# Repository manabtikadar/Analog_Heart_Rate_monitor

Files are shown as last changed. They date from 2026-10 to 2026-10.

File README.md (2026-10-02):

# ECG-Based Heart Rate Monitoring System

An analog ECG signal acquisition and conditioning system designed to capture, amplify, and filter the electrical signals generated by the human heart.

The project combines analog circuit design, PCB development, embedded hardware integration, and mechanical enclosure design to build a compact heart rate monitoring device.

---

## Project Overview

An electrocardiogram (ECG) records the electrical activity of the heart using electrodes placed on the body's surface. These signals have very low amplitudes and are susceptible to interference from power lines, electromagnetic sources, electrode contact variations, and body movements.

The objective of this project is to develop an analog signal conditioning circuit capable of amplifying weak ECG signals while reducing unwanted noise.

## System Architecture

The signal processing pipeline consists of multiple analog stages:

- **Signal Acquisition:** Collects electrical potential differences through body electrodes.
- **Signal Amplification:** Increases the amplitude of weak ECG signals using operational amplifier circuits.
- **Analog Filtering:** Attenuates unwanted frequency components and interference.
- **Embedded Hardware Integration:** Incorporates an ESP32 development module and display connections.
- **Signal Visualization:** Provides a display interface for presenting monitored signals and measurement information.

## Hardware Design

### Analog Circuit Design

The analog front-end is designed to handle low-amplitude ECG signals while accounting for noise and interference.

The circuit uses:

- Operational amplifiers for signal amplification.
- Resistor-capacitor networks for frequency-selective filtering.
- Feedback networks to control gain.
- Multiple signal conditioning stages to improve signal quality.

### PCB Development

The hardware was designed using **Altium Designer**, with a four-layer PCB architecture.

**PCB design highlights:**

- Two signal routing layers.
- Dedicated ground and power planes.
- Integrated ESP32 development module.
- On-board display connections and power routing.
- IC sockets and modular connectors for convenient maintenance.

The PCB was fabricated, and the components were assembled and soldered manually.

## Circuit Simulation and Validation

The analog circuit was modeled and evaluated using:

- **LTspice:** Analog circuit behavior and signal response analysis.
- **NI Multisim:** Circuit simulation and verification.

## Mechanical Enclosure

A custom enclosure was designed using **SolidWorks**.

**Design features:**

- Removable top cover for assembly and maintenance.
- Dedicated mounting space for the display and adjustment knobs.
- Ventilation openings for heat dissipation.
- Access points for the power supply and electrode connections.
- Compact design suitable for housing the integrated electronics.

## Tools and Technologies

| Category | Tools / Components |
|---|---|
| Circuit Design | Operational Amplifiers, Resistors, Capacitors |
| PCB Design | Altium Designer |
| Circuit Simulation | LTspice, NI Multisim |
| Embedded Hardware | ESP32 Dev Module |
| Mechanical Design | SolidWorks |
| Fabrication | PCB Fabrication, Manual Soldering, 3D Printing |

## Project Images

### PCB Implementation

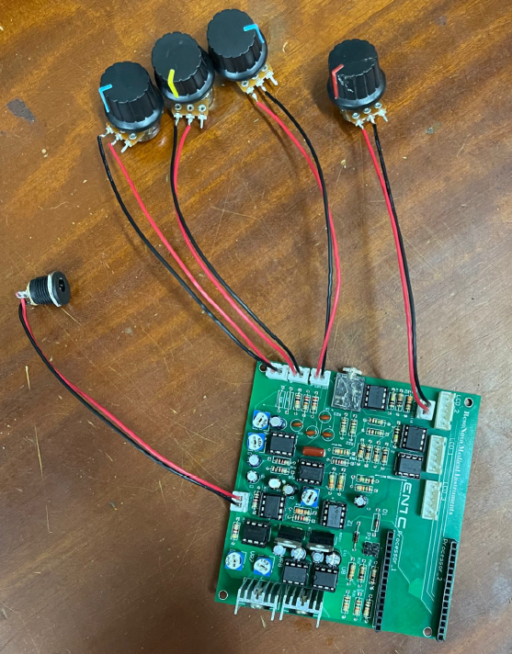
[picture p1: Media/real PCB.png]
Fabricated ECG PCB


### Enclosure Design

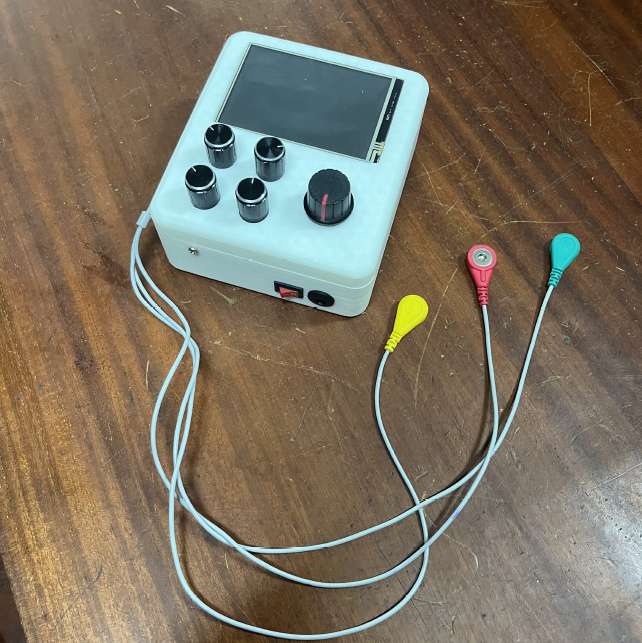
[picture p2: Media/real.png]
3D Printed Enclosure


## Key Learning Outcomes

- Analog signal amplification and filtering.
- ECG signal characteristics and noise sources.
- Multilayer PCB design and hardware integration.
- Circuit simulation and pre-fabrication validation.
- Mechanical enclosure design and prototyping.

## Contributors

- [Manab Tikadar](https://github.com/manabtikadar)

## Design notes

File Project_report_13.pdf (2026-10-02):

## Department of Electronic and Telecommunications Engineering

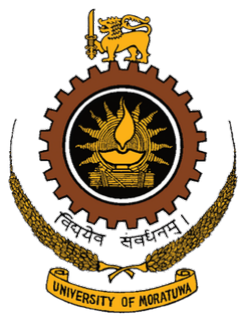
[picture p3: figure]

EN2091 Laboratory Practice and Project

Final Report

# ECG Heart Monitor

Charles J.

### Madugalle M.R.K.J.M.M.S.B

Kavishan G. T.
Wijesinghe C. D.

210079K
210351M
210285M
210720U

# Contents

ECG Heart Monitor - Resonova

## Abstract

Our project is regarding the development of a analog ECG heart monitor for real-time cardiac activity monitoring. Here we utilize only analog components to amplify heart-generated electrical
signals | and | for | signal | conditioning
to reduce noise. | It is then followed
by | analog-to-digital | conversion | and
subsequent | signal | processing | stages,
implemented | on | a | microcontroller.
Additionally, our project explores the integration of wireless communication for remote monitoring.

## 1 Introduction

An electrocardiogram (ECG) is a simple
diagnosis | technique | employed | to | assess
the heart’s electrical activity by detecting
electrical | signals | generated | during | each
heartbeat through electrodes fixed to the skin. The voltage difference between the right arm and left arm is magnified, incorporating a feedback mechanism through the right leg. ECG leads measure these voltages from the right arm, left arm, and right leg. The voltage signal’s amplitude ranges from 0.001 mV to 100 mV (typical value is 1 mV), with a frequency spanning from 0.01 Hz to 250 Hz. Amplifying this signal proves challenging due to the small amplitude of the raw ECG signals and subjection to corruption from various sources such as noise, power line interference, RF inteference, noise from electrode contact, stray capacitance, and bio signal artifacts induced by movements of the subject.

In our project we propse and implement a analog circuit to amplify the above eletrical signal and to perform filtering to reduce noise. We make use of only basic analog electrical devices such as resistors, capacitors and OpAmps in our design.

The below block diagram illustrates the stages of signal conditioning employed in our design.

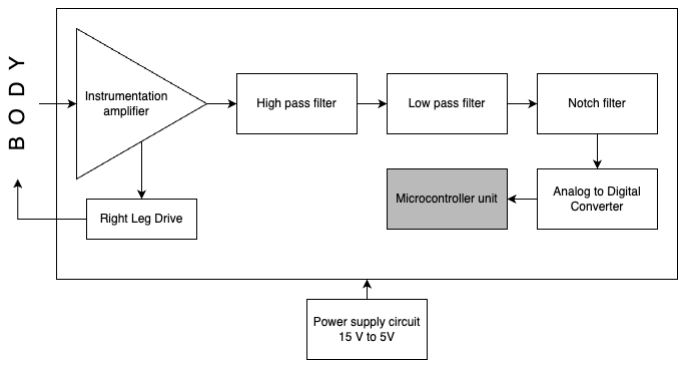
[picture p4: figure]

Figure 1: Block diagram of the circuit design

We implement the design of our circuit on a single PCB using the Altium PCB design software. All circuits were simulated
using | LTSpice | and | MultiSim | prior | to
implementation.

## 2 Functionality

### 2.1 Instrumentation amplifier

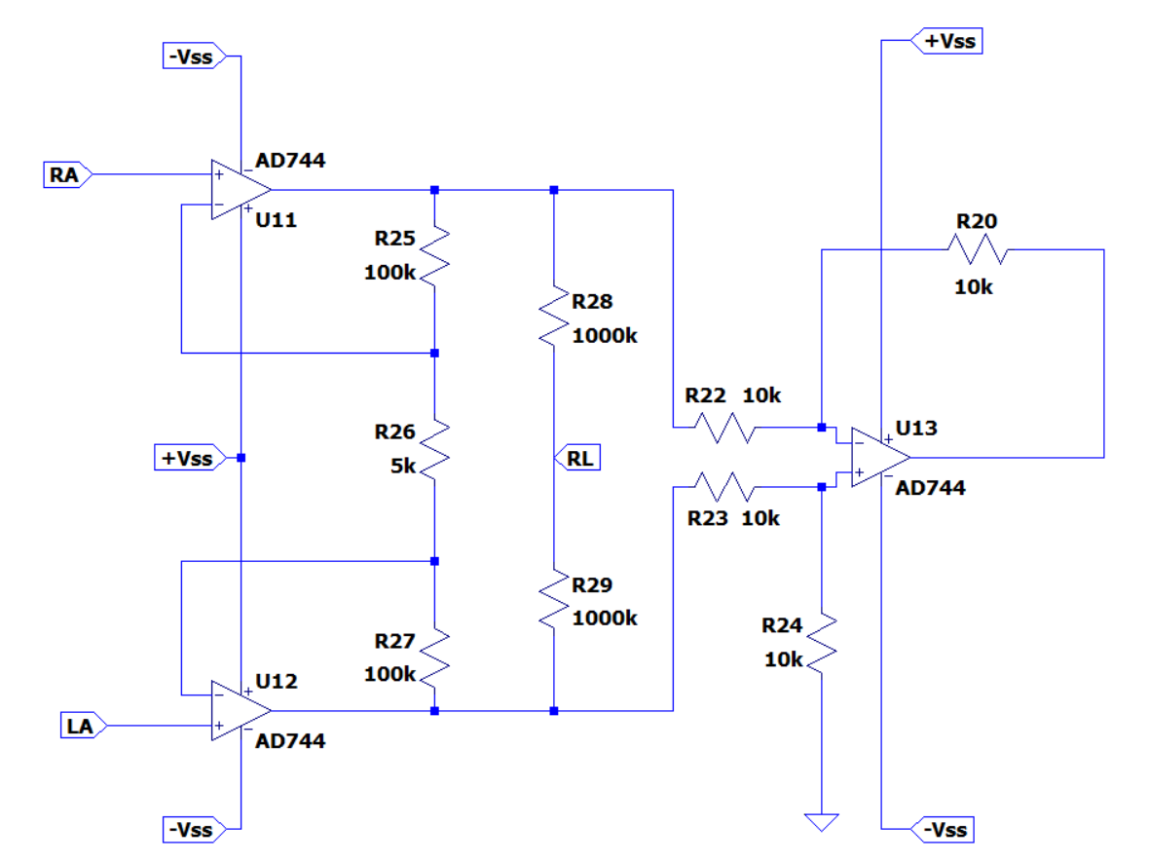
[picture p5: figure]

Figure 2: Instrumentation amplifier

The | primary | objective | of | the
Instrumentation | amplifier | is | amplifying
the small electrical signals generated by the
heart. | These ECG signals are typically in
the milli-volt range. | The instrumentation
amplifier amplifies this by amplifying the differential voltage between two electrodes while also rejecting common-mode inputs like interference from nearby power lines or

biosignal artifacts.

The proposed design of the instrumentation amplifier in our circuit operates using three TL071CP OpAmp ICs. We selected this IC because of its high Common Mode Rejection Ratio (CMRR). It has a minimum CMRR of 95 dB which was suitable enough for the amplification process. The input to the circuit is fed through two ECG leads. The gain can be adjusted using the variable resistor in the middle. We found through fine-tuning that preferred gain is 35.6.

### 2.2 Right Leg Drive

The Right Leg Drive (RLD) circuit is used to minimize the common-mode signal between the two input electrodes. This is done by taking the original signal, inverting and amplifying it and sending back to the body through the right leg. In the RLD configuration we use two TL072CP OpAmps; one acting as a unity gain buffer and the other as an inverting amplifier. We also include a high impedance resistor (0.5MΩ) before injecting the signal to the body for patient protection purposes. The gain of the RLD stage is 67.

### 2.3 Filter specifications

The selection of proper cutoff frequencies for filtering was a pivotal decision. The American Heart Association (AHA) suggests a minimum bandwidth of 150Hz for individuals aged 12 to 16 years and a minimum bandwidth of 125Hz for adults[1]. Based on this recommendation and analyzing several other designs, we chose the range of 0.01 Hz - 170 Hz to preserve accuracy while maintaining minimal noise.

We decided on implementing filter circuits using active filters to prevent loading effect. Furthermore, we used TL072CP OpAmp ICs when implementing the filter circuits.

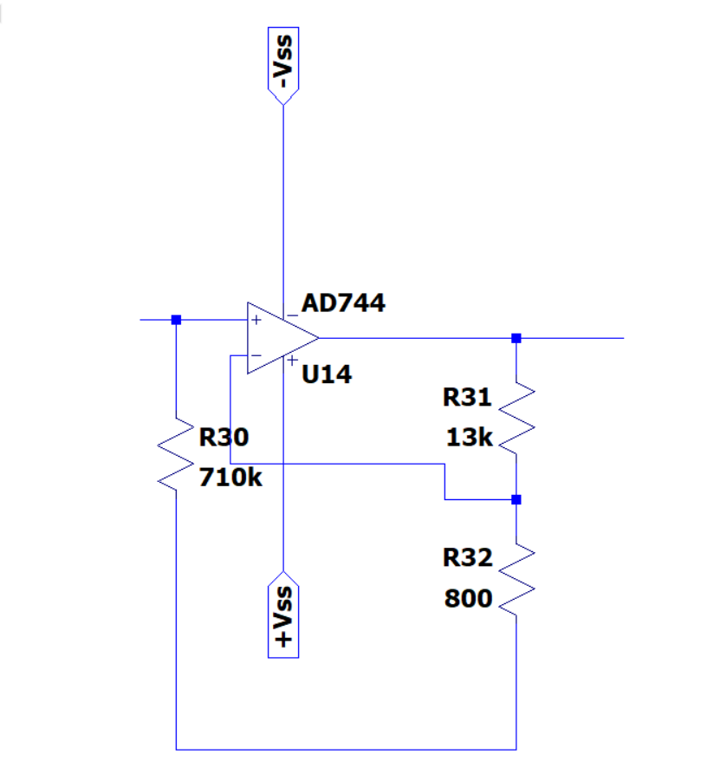
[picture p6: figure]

Figure 3: High-pass filter

### 2.4 High-pass filter

A first-order active high-pass filter is a circuit was proposed to allow signals with frequencies higher than 0.01 Hz to pass through while attenuating lower-frequency signals. The main objective was this to remove the DC shift of the original electrical signal.

For a high-pass filter, we used a first order active filter since the precision and the rapid change of the transition band was not significant. The cutoff frequency (fc) of a first-order high-pass filter is given by the formula:

| fc =
| 1 2πRC

### 2.5 Low-pass Filter

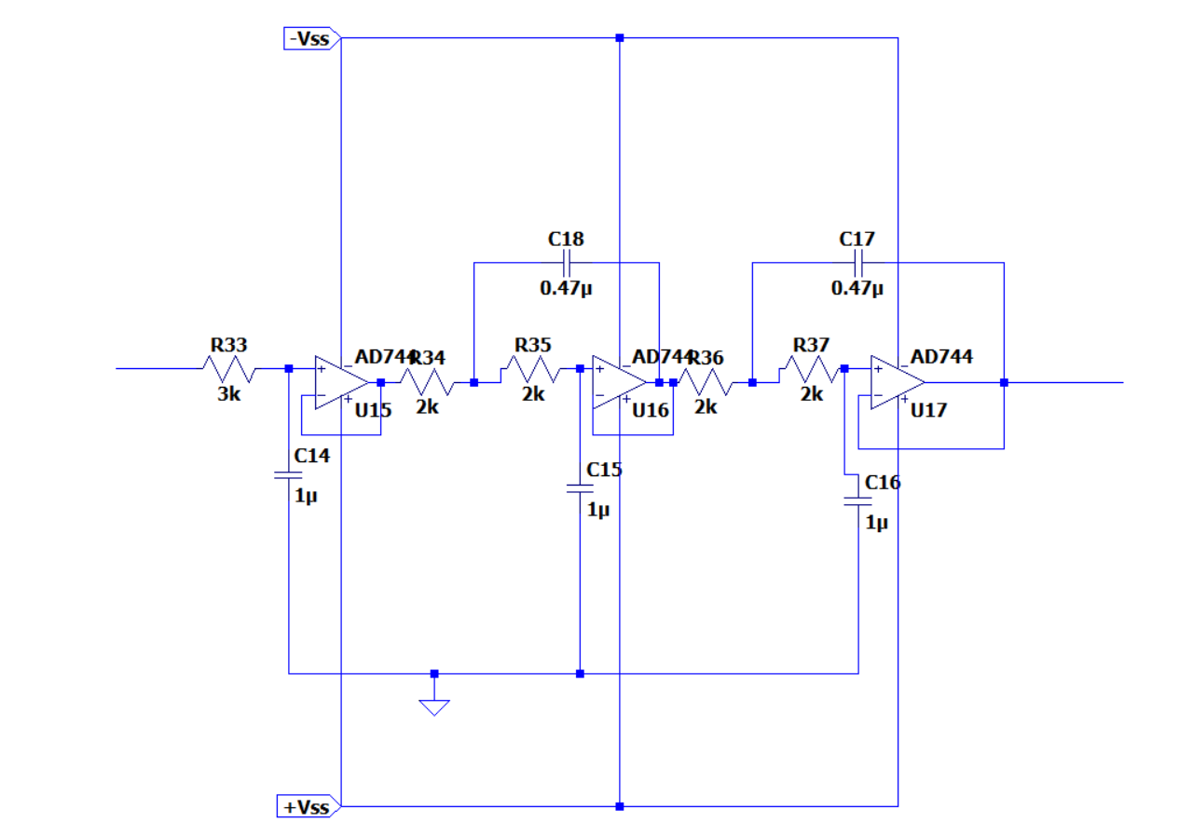
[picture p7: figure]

Figure 4: Low-pass filter

We chose our cutoff frequency of the low-pass filter as 170 Hz. We also decided that the transition needs to be as steep as possible therefore adapted a 5th order configuration. The Bessel filter yields stable transient and constant group delay [2].

We realized the 5th order filter by cascading a first order filter with two 2nd order filters with Sallen-Key topology. The gain of the filter is unity. The following formula was used to determine the capacitor and resistances needed.

fc =

1
2π

√
R1R2C1C2

### 2.6 Notch filter

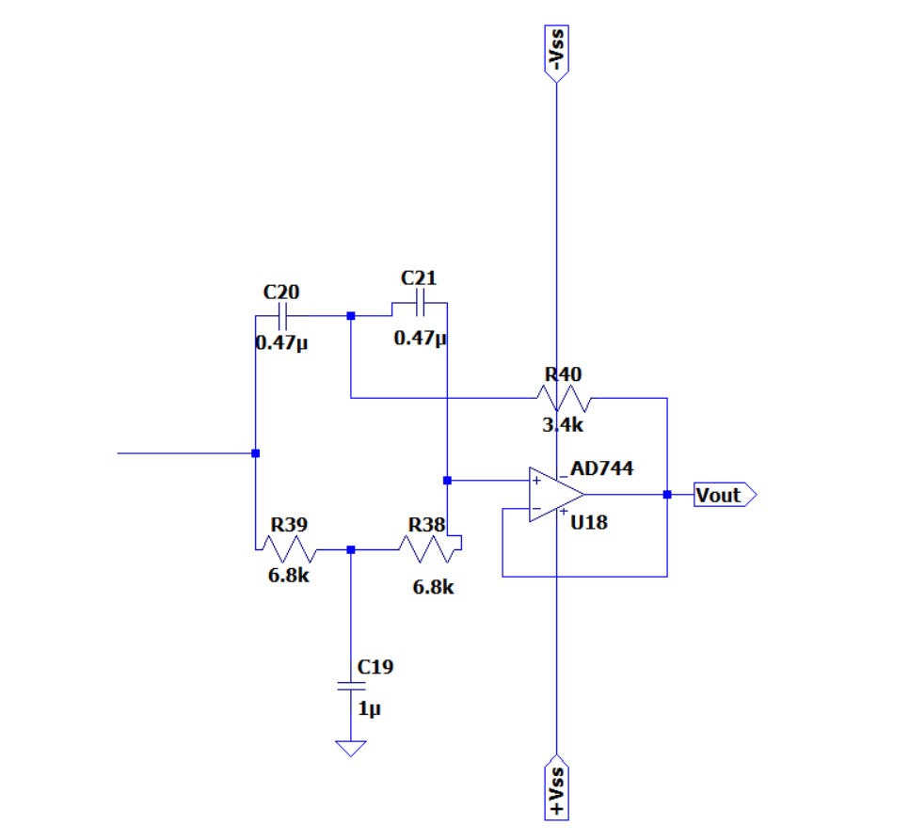
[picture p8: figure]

Figure 5: Notch filter

The purpose of the notch filter (band reject filter) is to remove the spike at 50-60 Hz in the spectrum of the signal. This spike is resulted due to the power line interference. It is realized by a twin-T RC circuit including a TL072CP OpAmp. This filter configuration is an active filter. Also a quality control circuit is appended to the filter to optimize the steepness of the transition band by adjusting the Q-factor. The resistances are selected to be adjustable using variable resistors so that the exact power line interference frequency can be cut off. The gain from the notch filer is unity while a non-unity gain is added by the quality circuit.

The cutoff frequency of the notch filter can be approximated as using the following.

fn =

1
2πRC

Additionally, the Q-factor can be approximated using the below formula.

Q =

R1
2(R1 − R2)

### 2.7 Power circuit

The OpAmp ICs in all circuits require +5v and -5V supply voltage for preferred operation. To synthesize these voltages we propose the power circuit shown in figure 6. The input to the power circuit is taken through a 15V DC power adapter bought from the market. This 15V input voltage is then broken down to into two 7.5V potentials of opposite polarity. The LM7805 and LM7905 regulators are used to obtain stabilized voltages of +5V and -5V. Push-pull transistor configuration is used to balance the load. Capacitors are used for stabilization.

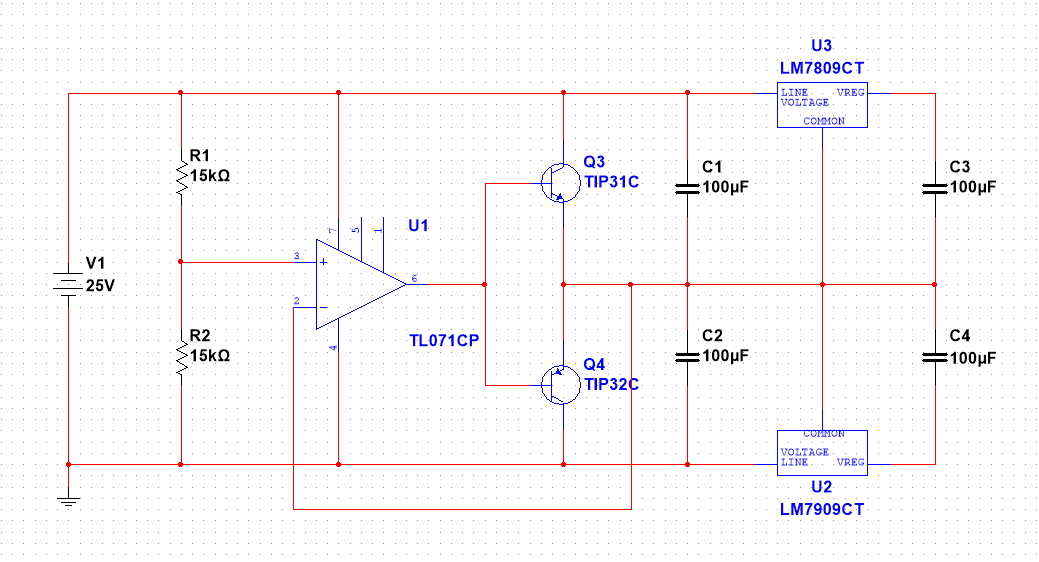
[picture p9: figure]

Figure 6: Power circuit

### 2.8 Analog to Digital Conversion Pre-conditioning circuit

The | signal | is | taken | into | the | ESP32
Micro-controller through one of the chip’s inbuilt Analog to Digital conversion pins. The constraint for ADC conversion is to provide signals only between 0-3.3V to the input pin. Since the notch filter output clearly exceeds this range we implemented a level shifting circuit to shift and scale down the output signal to the 0-3.3V range. The proposed circuit is shown in figure 7.

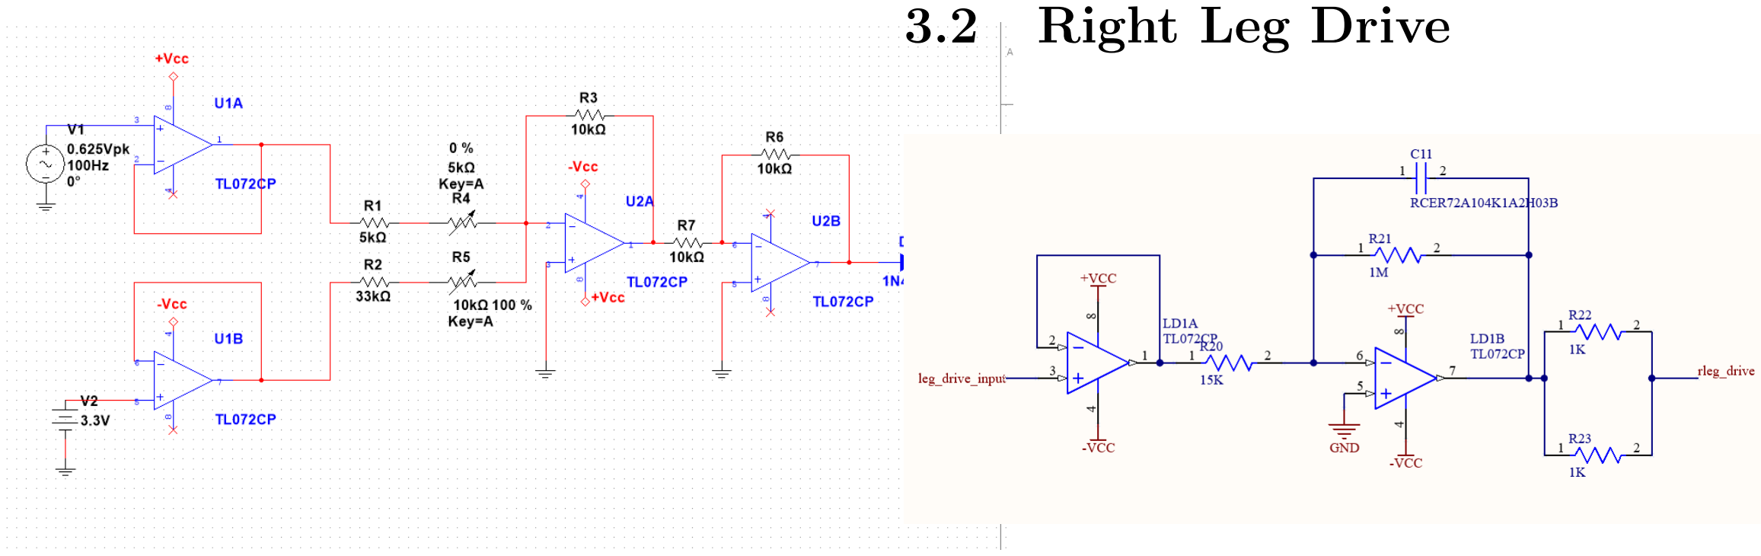
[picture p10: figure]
3.2 Right Leg Drive

Figure 7: Shifting and scaling circuit

## 3 Design Parameters

The following are the gain and frequency response calculations for individual stages using the PCB schematics.

### 3.1 Instrumentation Amplifier

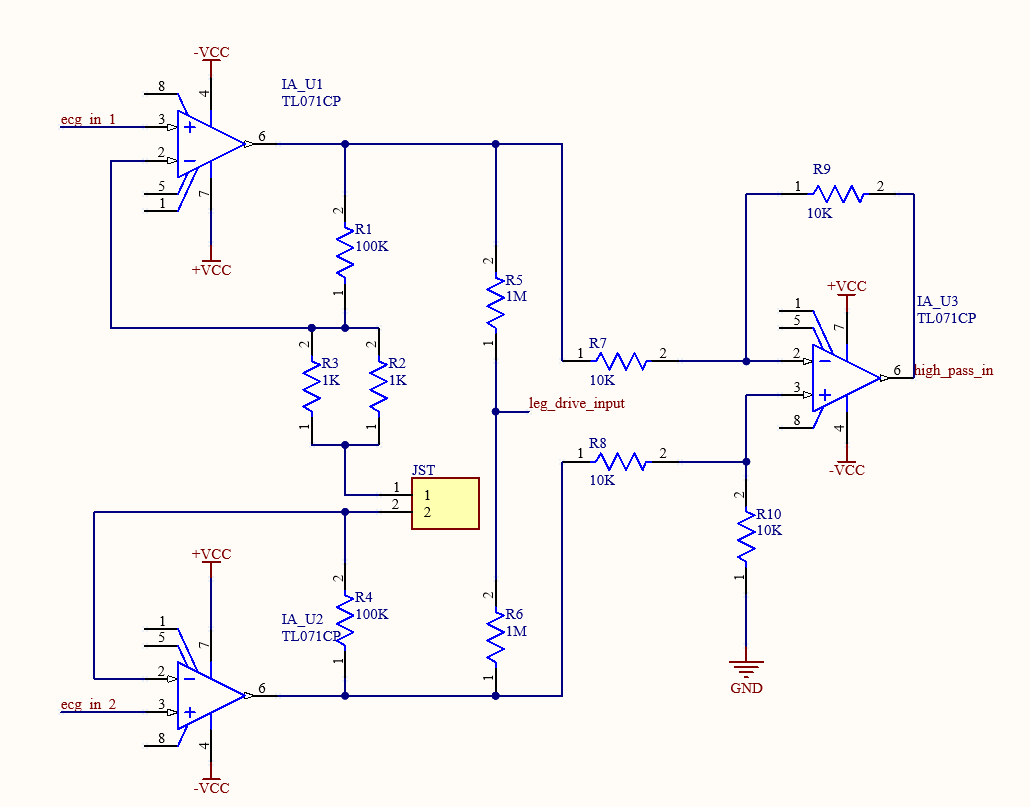
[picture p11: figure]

Figure 8: Instrumentation amplifier PCB Schematic

Gain

Gain =

R1 + R4 + RA
RA

!
= 1 +

200
RA

!

Here the overall impedance of R2, R3 and variable resistor is taken as RA. By changing the resistance RA we can obtain a gain within 20-400.

Figure 9: Right leg drive PCB schematic

Gain

Gain =

R21

R20

=

1MΩ
15kΩ

= 67

The right leg drive circuit outputs a signal with unity gain and 180° phase delay.

### 3.3 High-pass filter

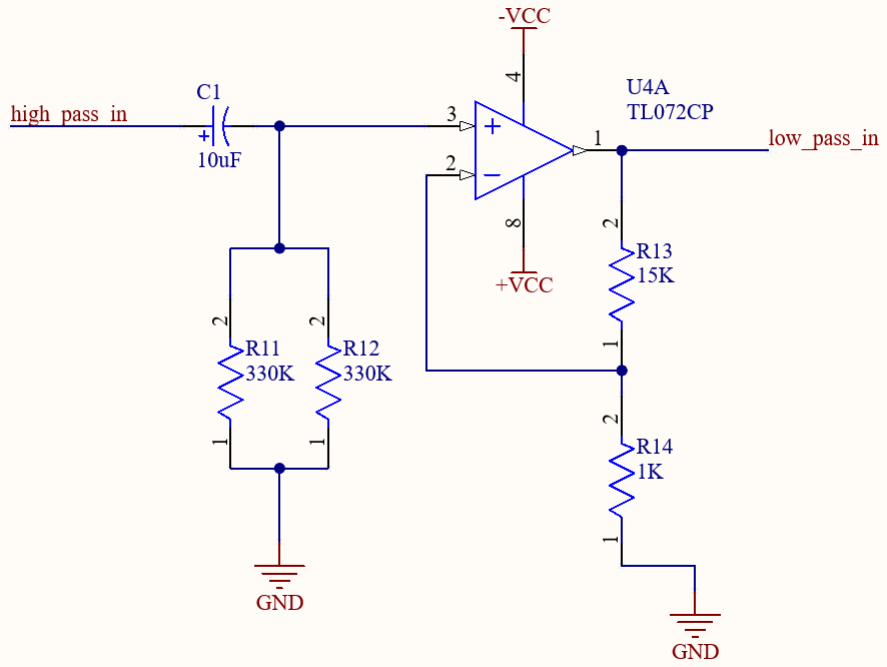
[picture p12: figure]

Figure 10: High-pass filter circuit PCB Schematic

Gain

Gain = 1 +

R13

R14 !
= 1 +

15kΩ
1kΩ

!
= 16

Cut-off frequency

fc =

1
2πRC =

1
2π × 10µF × 165kΩ
fc = 0.096Hz

### 3.4 Low-pass filter

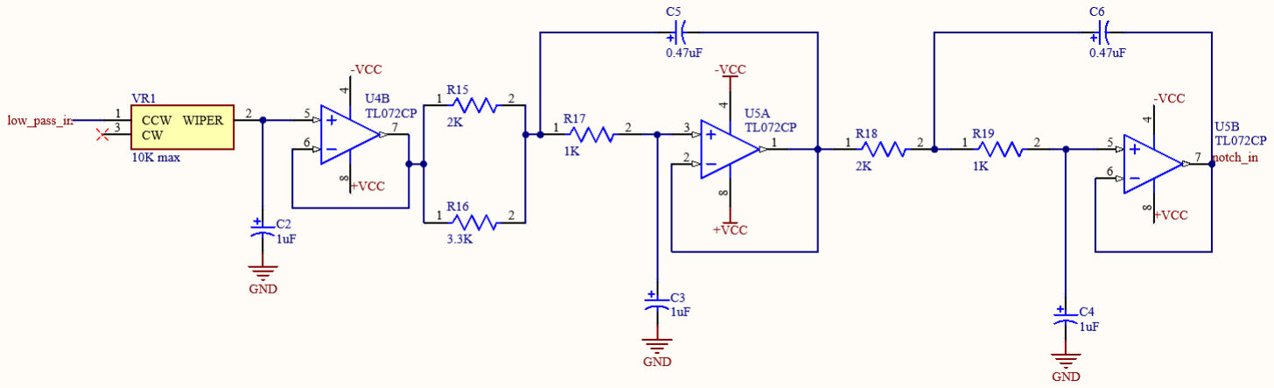
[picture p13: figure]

Figure | 11: | Low-pass | filter | PCB
Schematic

The gain if the low-pass filter is unity.
The cut-off frequency of the low-pass filter can be calculated from the RC values of the last OpAmp’s configuration.

Cut-off frequency

fc = | | 1
| 2π

√
2kΩ × 1kΩ × 0.47µF × 1µF
| | fc = 164Hz

This is close the required cut-off value of 170 Hz.

### 3.5 Notch filter

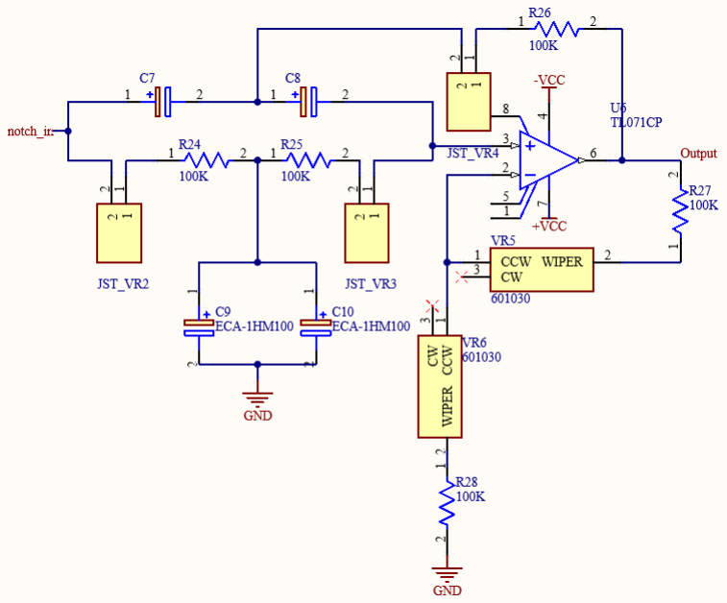
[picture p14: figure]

Figure 12: Notch filter PCB Schematic

Gain
The gain of the notch filter is only due to the quality circuit (Due to the impedences VR5 and VR6). We fine-tuned the values of these variable resistors to obtain the preferable gain as follows.

Gain = 1 +

2.5kΩ
4kΩ

!
= 1.625

Cut-off frequency

The cut-off frequency of the circuit can be varied according to the power-line noise existing. We therefore do not calculate the exact cut-off frequency. But the resistor values we used are shown in the PCB schematic.

## 4 PCB design

All circuits mentioned above were realized and fabricated on a single PCB. The PCB was deisgned using Altium Designer PCB Software. In our design approach, we employed 4 layers to minimize interference. This consists of two signal layers, the ground layer and the power layer. The PCB was designed in a way that the processor (ESP32 Dev Module) is also mounted on the same PCB. The PCB and display wiring is also included within the PCB routing.

After the fabrication, the relevant components are soldered by hand to the PCB. For convenience of replacement, we soldered IC bases and mounted the ICs onto them. Additionally, we used JST cables and pin headers for easy replacement. The final appearance of the PCB after soldering is shown in Figure 11.
PCB layout diagrams for individual layers are shown in the Appendix I.

## 5 Enclosure design

The SolidWorks CAD software was utilized to design the enclosure. This enclosure has a removable top lid, facilitating the fixation and replacement of components as needed. To prevent damage to the components, there are strategically placed ventilation and airflow, allowing heat to dissipate to the outside. The top lid houses the display and knobs for filter

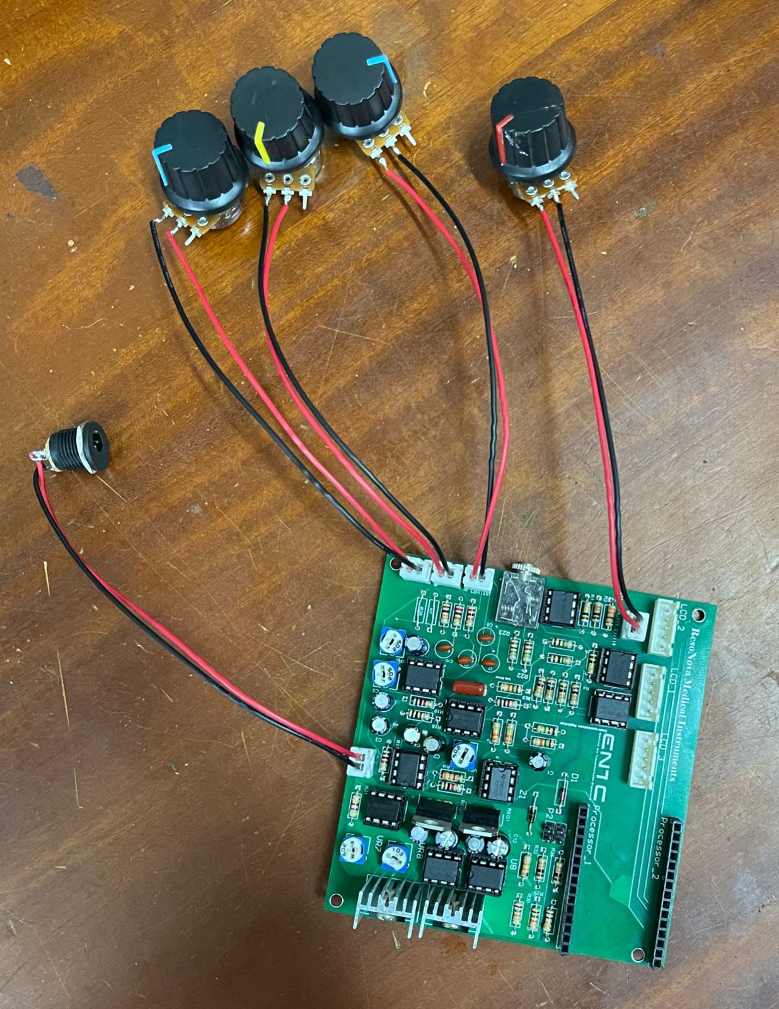
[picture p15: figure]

Figure 13: PCB after soldering all the components

tuning. A power on/off switch is positioned on the side. The enclosure is equipped with holes for power adapter input and 3.5mm jack connections.
3D views and drawings of the enclosure design are shown in the Appendix I.

## 6 Micro-controller programming

The input taken into the ESP32 Dev Module is then processed to be drawn on to a TFT LCD dislpay. The micro-controller is programmed using the Arduino IDE with C++ programming language. We used the MCUFRIEND kbv Arduino library to operate the TFT display. The full code for the program is shown in the Appendix III and is also uploaded to Github.

## 7 Simulating circuits and testing

All circuits have been simulated on LTSpice and MultiSim simulation software before implementing physically. Thereafter we realized the circuits on breadboards and tested their functionalities individually as well as cascaded. The simulation results and breadboard implementation is shown in the Appendix II.

## 8 Final prototype

Shown below is the working finished prototype with the PCB mounted and components assembled.

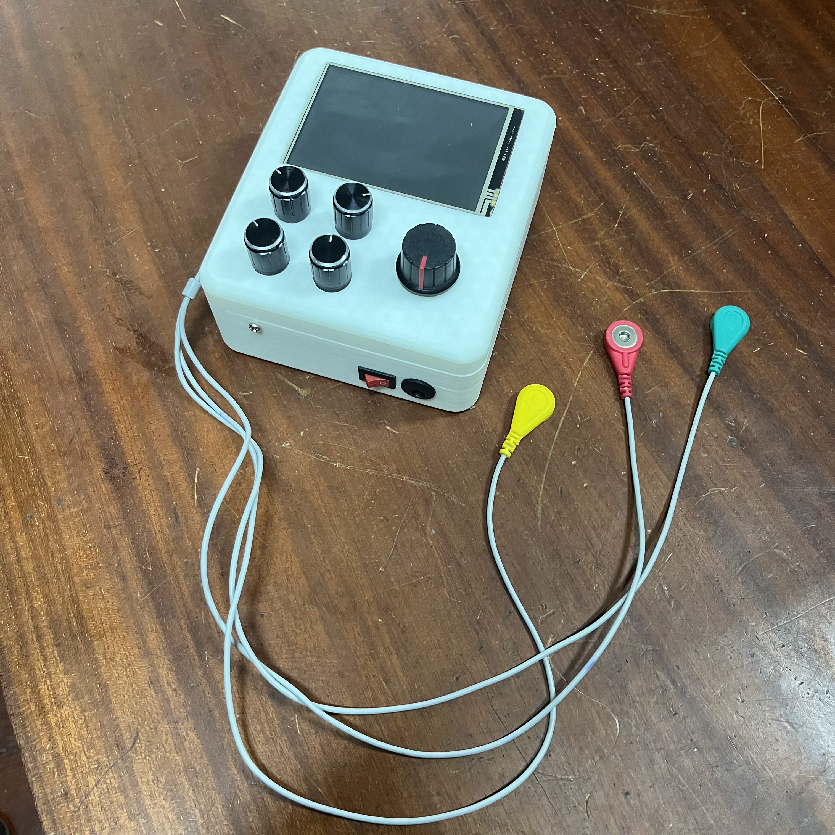
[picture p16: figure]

Figure 14: Final device prototype

## 9 Task allocation

Charles J. - PCB soldering, Notch circuit optimization
Kavishan G.T. - PCB Design, Filter circuits optimization
Madugalle M.R.K.J.M.M.S.B - Enclosure design, Intrumentation amplifier optimization Wijesinghe C.D. - ESP32 programming, RLD circuit optimization

## 10 Resources

GitHub repository including all the schematic files, PCB and enclosure design files and code
can be found here:
github.com/Sajitha-Madugalle/Heart Rate Monitor.

## 11 References

[1] P. R. Rijnbeek, | J. A. Kors, | and
M. | Witsenburg, | “Minimum | Bandwidth
Requirements for Recording of Pediatric
Electrocardiograms,” Circulation, vol. | 104,
no. | 25, pp. | 3087–3090, Dec. | 2001, doi:
https://doi.org/10.1161/hc5001.101063.
[2] J. Karki, “Active Low-Pass Filter Design.” Accessed: Dec. 05, 2023. [Online]. Available: www.ti.com/lit/an/sloa049d/sloa049d.pdf
[3] “Design of an ECG sensor circuitry for cardiovascular disease diagnosis,” International Journal of Biosensors & Bioelectronics, vol. Volume 2, no. Issue 4, May 2017, doi: https://doi.org/10.15406/ijbsbe.2017.02.00032.

## Appendix I - PCB Layout and Enclosure design

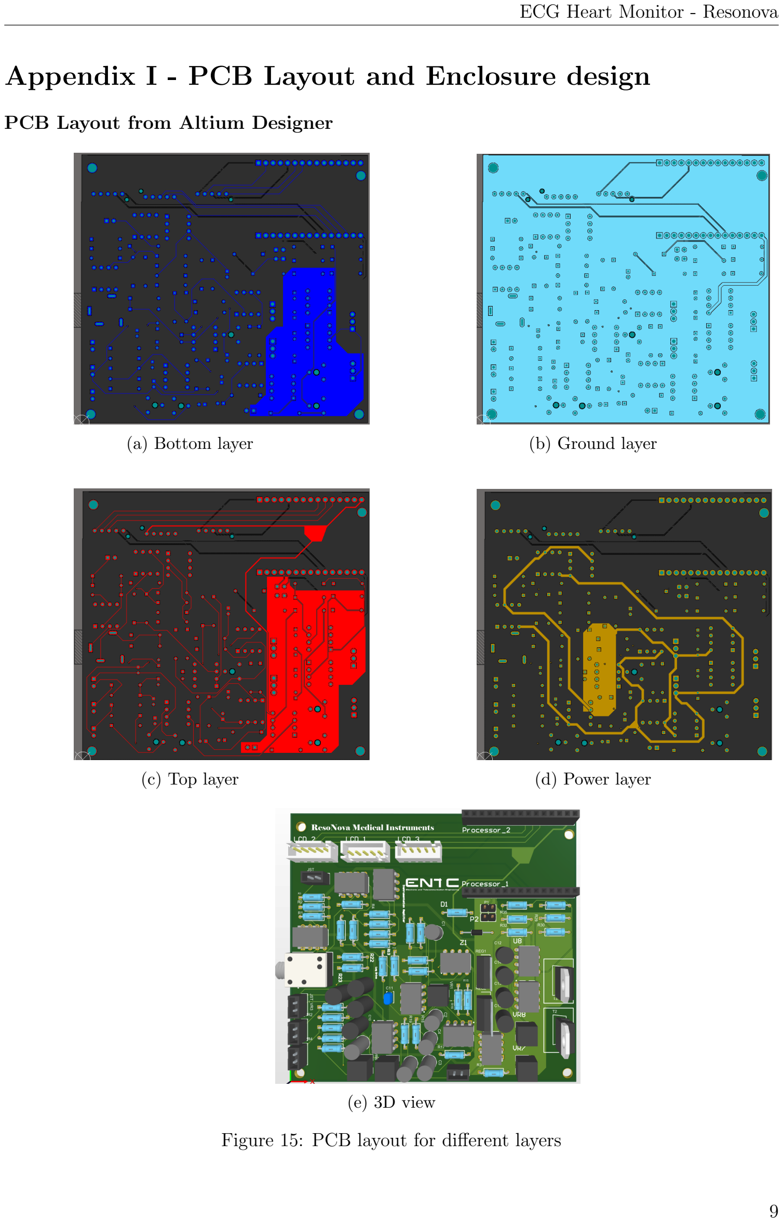
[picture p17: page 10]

PCB Layout from Altium Designer

(a) Bottom layer | (b) Ground layer
(c) Top layer | (d) Power layer
(e) 3D view

Figure 15: PCB layout for different layers

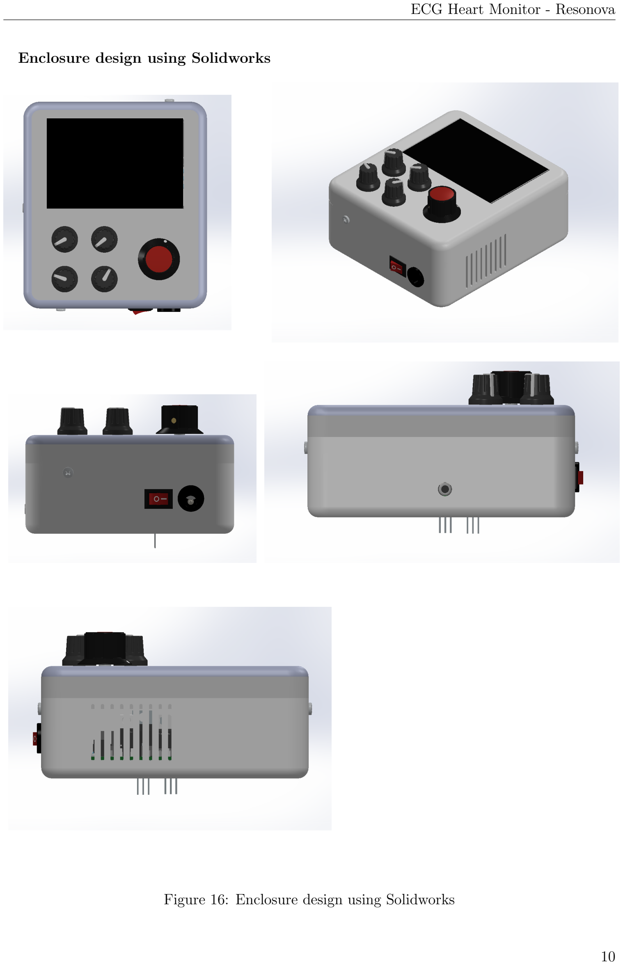
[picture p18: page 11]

Enclosure design using Solidworks

Figure 16: Enclosure design using Solidworks

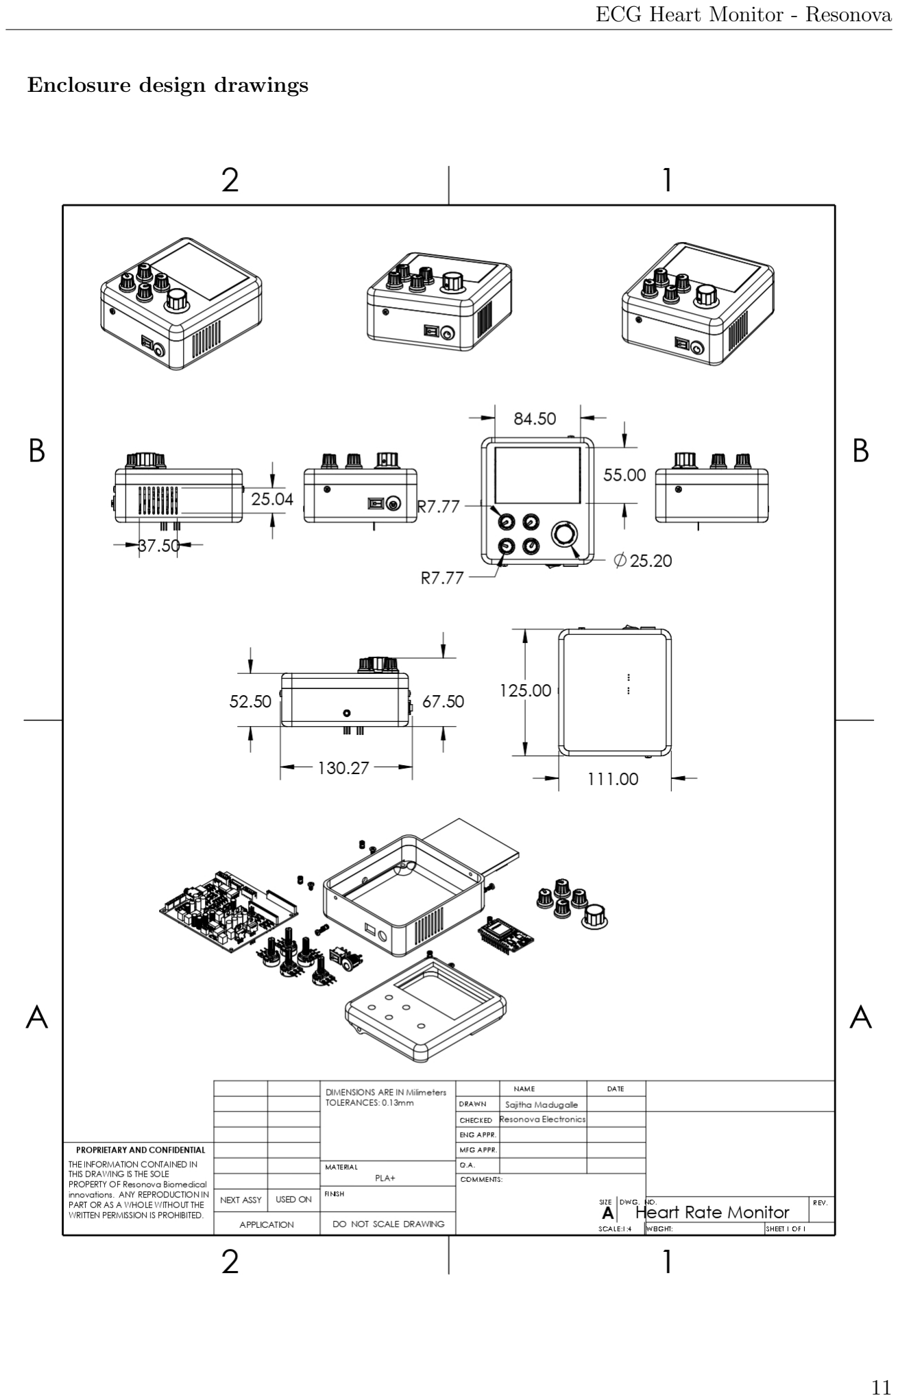
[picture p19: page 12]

Enclosure design drawings

## Appendix II - Simulation and Testing

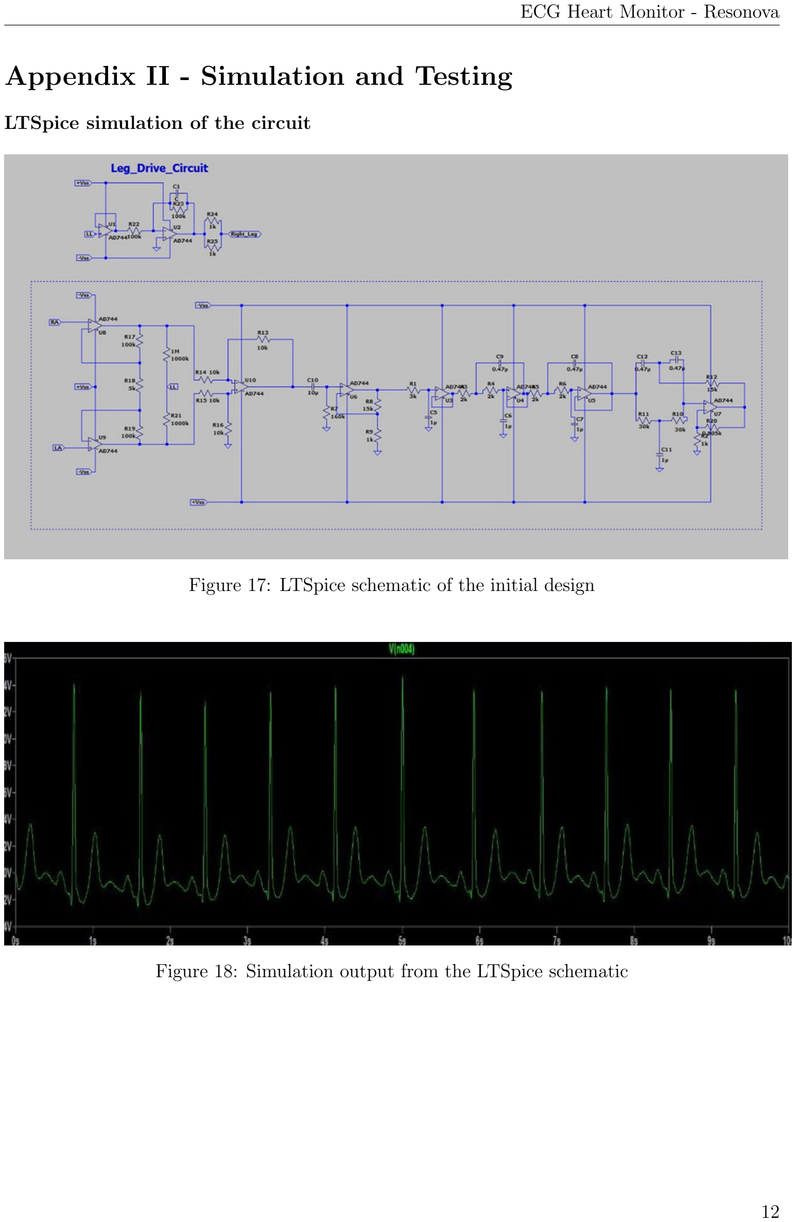
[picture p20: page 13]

LTSpice simulation of the circuit

Figure 17: LTSpice schematic of the initial design

Figure 18: Simulation output from the LTSpice schematic

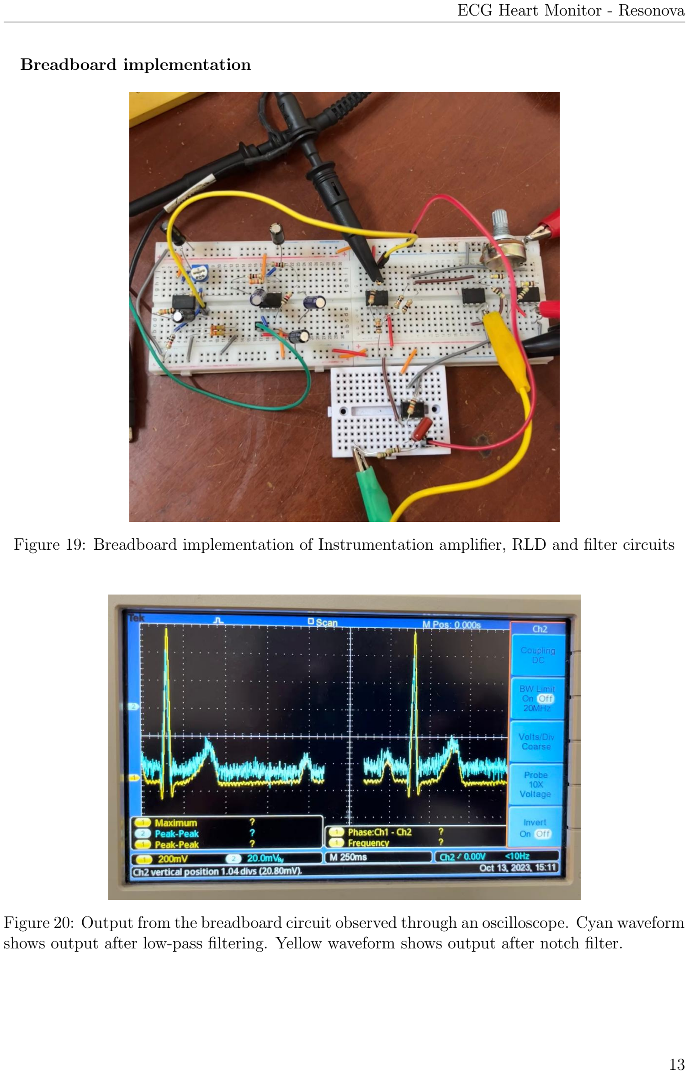
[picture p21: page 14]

Breadboard implementation

Figure 19: Breadboard implementation of Instrumentation amplifier, RLD and filter circuits

Figure 20: Output from the breadboard circuit observed through an oscilloscope. Cyan waveform shows output after low-pass filtering. Yellow waveform shows output after notch filter.

## Appendix III - Microcontroller code

ESP32 Dev Module C++ code

1 | # include < Adafruit_GFX .h >
2 | # include < MCUFRIEND_kbv .h >
3 | MCUFRIEND_kbv tft ;

4

5
6 | // Define color codes
7 | # define BLACK 0 x0000
8 | # define BLUE 0 x001F
9 | # define GREEN 0 x07E0
10 | # define RED 0 xF800
11 | # define WHITE 0 xFFFF

12
13 | // Define variables for time intervals
14 | unsigned long previousMillis1 , previousMillis2 = 0;
15 | const long interval1 = 2;
16 | const long interval2 = 5;

17
18 | void setup ( void )
19 | {
20 | Serial . begin (9600) ;

21
22 | // Initiate the display
23 | uint16_t ID = tft . readID () ;
24 | Serial . println (" Example : Font_simple ") ;
25 | Serial . print (" found ID = 0x") ;
26 | Serial . println ( ID , HEX ) ;
27 | if ( ID == 0 xD3D3 ) ID = 0 x9481 ; // force ID if write - only display
28 | tft . begin ( ID ) ;

29
30 | // Set screen orientation
31 | tft . setRotation (1) ;
32 | tft . fillScreen ( BLACK ) ;

33
34 | // Draw the grid
35 | drawGrid () ;
36 | }

37
38 | void loop () {
39 | unsigned long currentMillis = millis () ;

40
41 | // Task1 - Draw ECG graph
42 | if ( currentMillis - previousMillis1 >= interval1 ) {
43 | previousMillis1 = currentMillis ;
44 | runECG () ;
45 | }
46 | }

47
48 | void drawGrid () {
49 | // Clear screen
50 | tft . fillScreen ( BLACK ) ;
51 | // Set text
52 | tft . setCursor (20 , 20) ;
53 | tft . setTextColor ( WHITE ) ;
54 | tft . setTextColor ( WHITE , BLACK ) ;

55 | tft . setTextSize (3) ;
56 | tft . println ("ECG") ;

57
58 | // Draw vertical lines
59 | for (int i = 1; i <= 6; i ++) {
60 | tft . drawLine (80 * i ,0 ,80* i , 320 , BLUE ) ;
61 | }

62
63 | // Draw horizontal lines
64 | for (int j = 1; j <= 4; j ++) {
65 | tft . drawLine (0 ,80 *j ,480 , 80* j , BLUE ) ;
66 | }
67 | }

68

69
70 | void runECG () {
71 | // Read analog value from ADC pin
72 | long ecgValue = analogRead (34) ;

73
74 | // Normalize the value read to it screen size
75 | int normalizedVal = map ( ecgValue , 0 , 4095 , 0 , 320) ;

76
77 | static int lastX = 0;
78 | static int lastY = tft . height () /2 + 50;
79 | int x = lastX + 2;
80 | int y = tft . height () - normalizedVal ;

81
82 | // Reset cursor if reached the right end of scren
83 | if ( x >= tft . width () ) {
84 | x = 0;
85 | drawGrid () ;
86 | lastX = 0;
87 | lastY = tft . height () /2 + 50;

88
89 | }

90
91 | // Draw ECG line
92 | tft . drawLine ( lastX , lastY , x , y , GREEN ) ;
93 | lastX = x ;
94 | lastY = y ;
95 | }

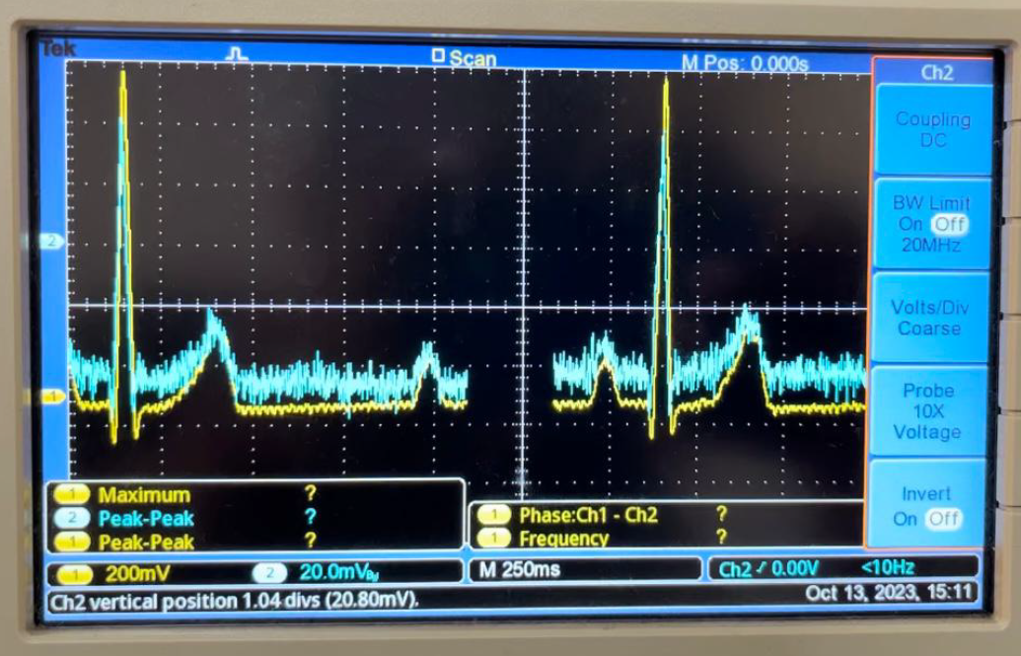
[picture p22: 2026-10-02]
Media/ECG_osci.png

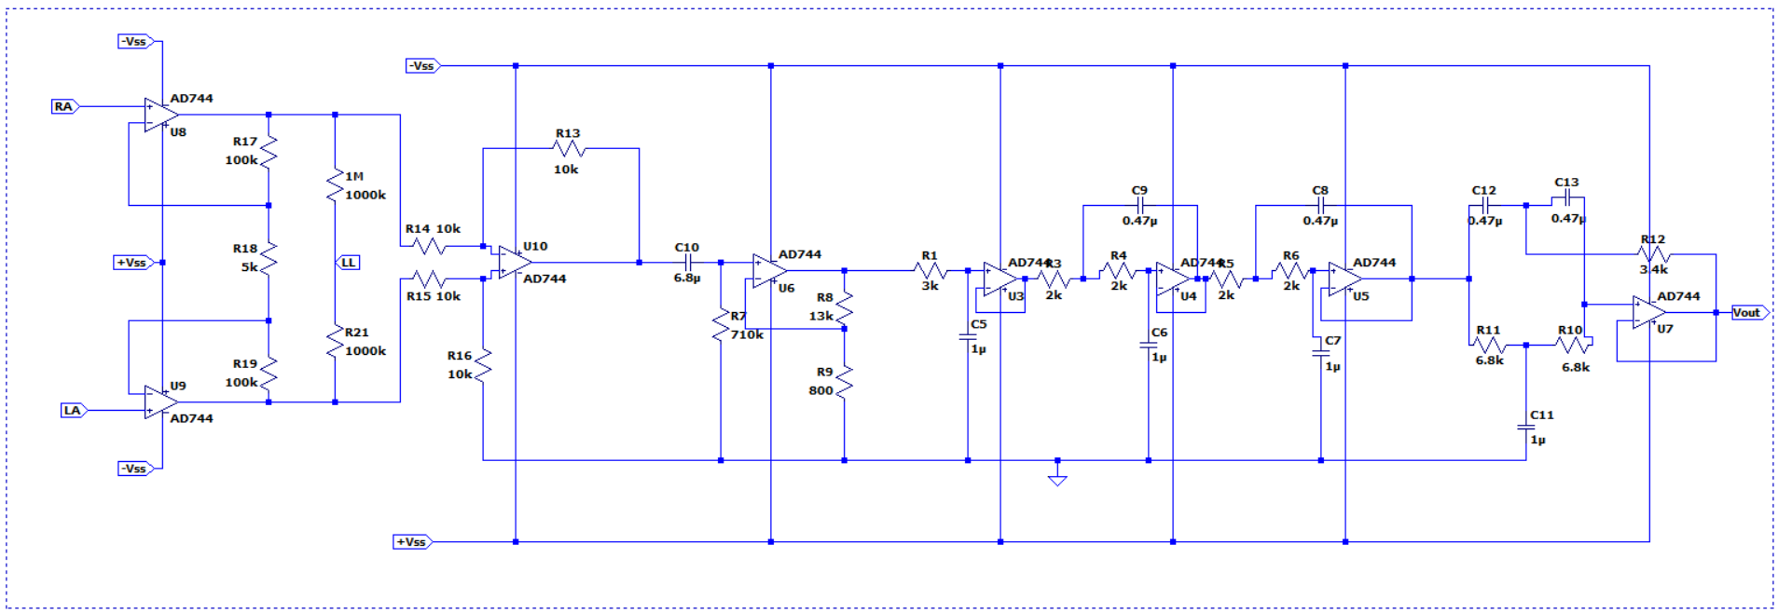
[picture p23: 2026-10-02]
ECG_circuit_diagram.png

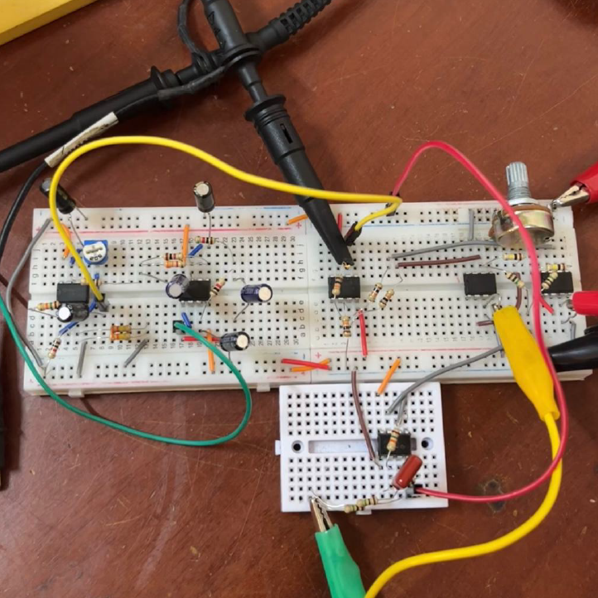
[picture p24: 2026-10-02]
Media/ECG_breadboard.png

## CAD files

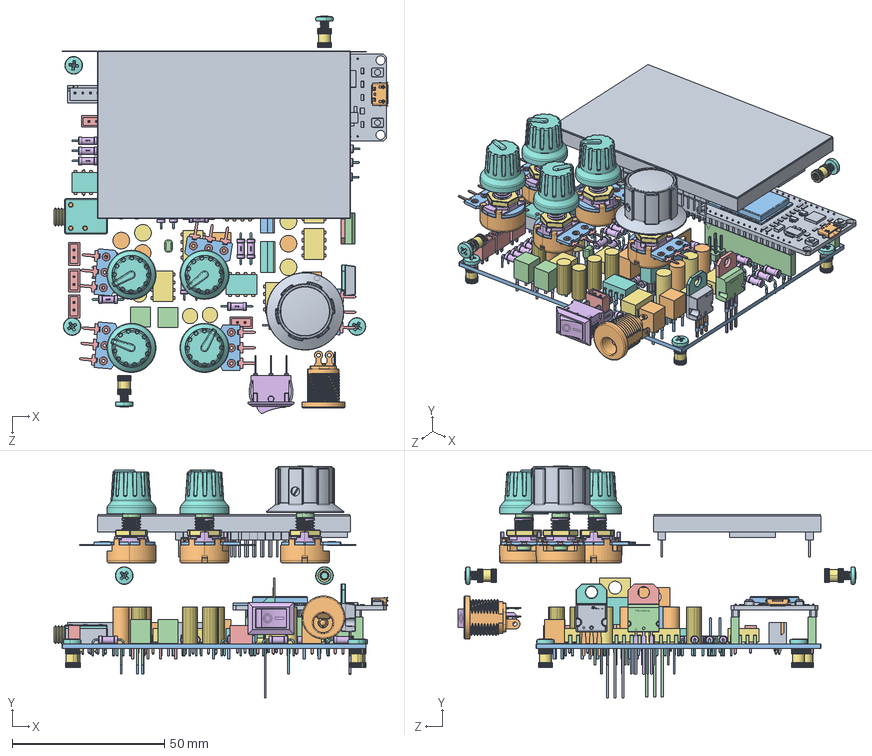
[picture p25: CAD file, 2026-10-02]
Enclouser Design/Heart Rate Monitor.SLDASM
109.6 x 76.1 x 130.5 mm
3.5 TFT LCD shield.stp
PotentiometerCasing.STEP x 5
PotentiometerPCB.STEP x 5
PotentiometerShaft.STEP x 5
PotentiometerTerminal.STEP x 15
PotentiometerThreadPlate.STEP x 5
PotentiometerNut.STEP x 5
Rotary Knob.step x 4
Cliff - FC1616 red.stp
DC jack.step
Body.step x 2
LeadsArray.step x 2
1.step x 36
2.step x 36
3.step x 36
6064575920.step x 2
6064576000.step
6130xx11121_PIN.step x 4
61300211121-0.step x 2
Body-1.step x 3
LeadsArray-2.step x 3
1-4.step
2-5.step
35RAPC3BH3.step
3-6.step
Switchcraft.step
Body-7.step
Logo1.step
Leads.step
Body-8.step
Sweep1.step
Sweep2.step
Body-9.step x 3
Leads-10.step x 3
Extruded.step x 48
Extruded-11.step x 48
Extruded-12.step x 48
Extruded-13.step x 6
2-14.step
3-15.step
4.step
STM Logo.step
STMicroelectronics TIP31C 1.step
STMicroelectronics TIP31C 2.step
STMicroelectronics TIP31C 3.step x 3
Tab.step
Body-16.step
PinsArray.step
Tab-17.step
Body-18.step
PinsArray-19.step
Body-20.step
LeadsArray-21.step
SimpleBody.step x 3
Pin1.step x 3
Pin2.step x 3
SimpleBody-22.step x 5
Pin1-23.step x 5
Pin2-24.step x 5
Body-25.step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

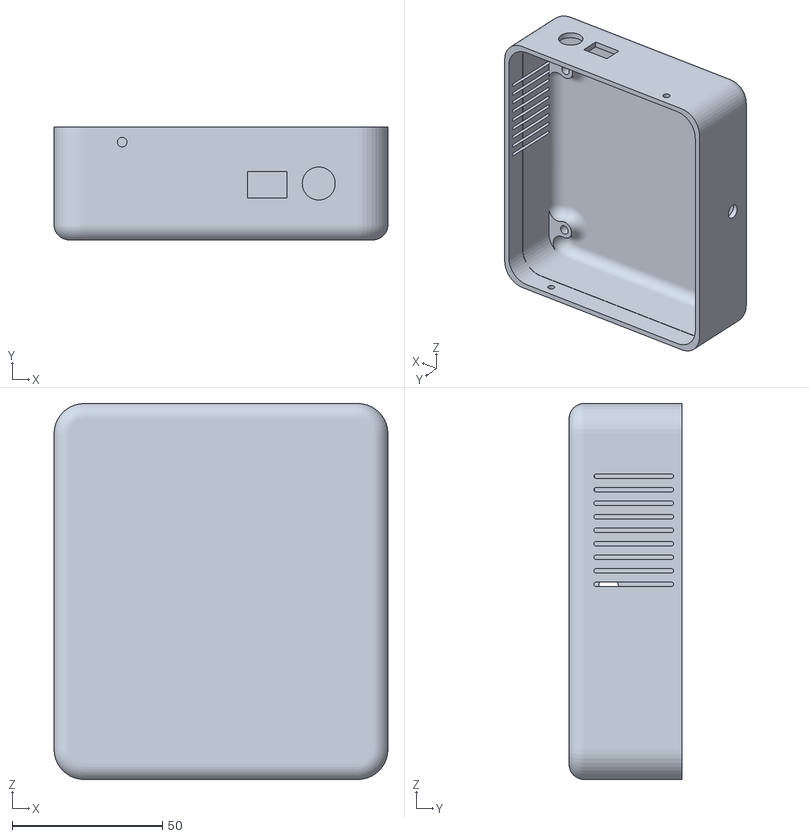
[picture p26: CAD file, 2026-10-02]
Enclouser Design/Base3D.STL
111.0 x 37.5 x 125.0

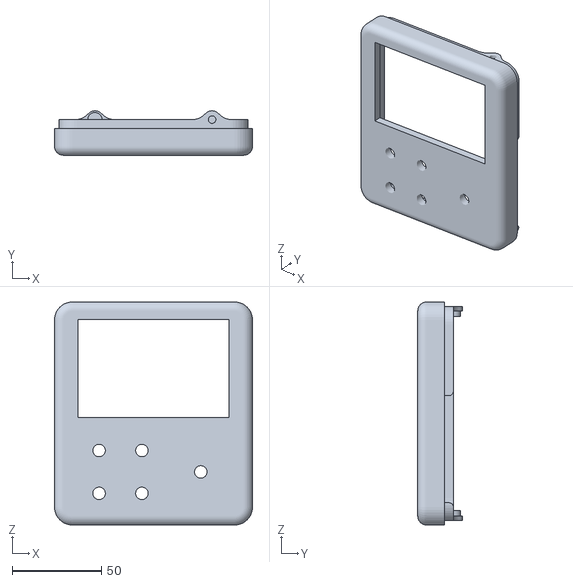
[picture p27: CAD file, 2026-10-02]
Enclouser Design/Lid3D.STL
111.0 x 25.0 x 125.0

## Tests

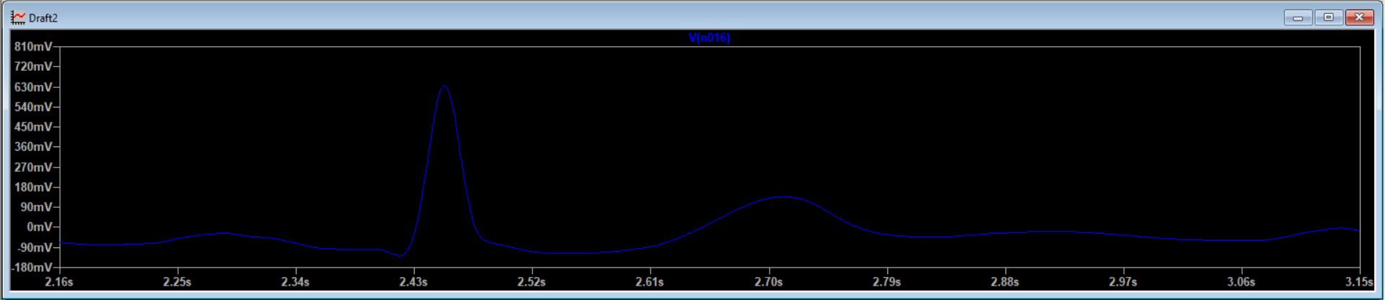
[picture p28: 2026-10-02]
Simulations/LTspice_Simulations/Simulation results/Smoothed.png

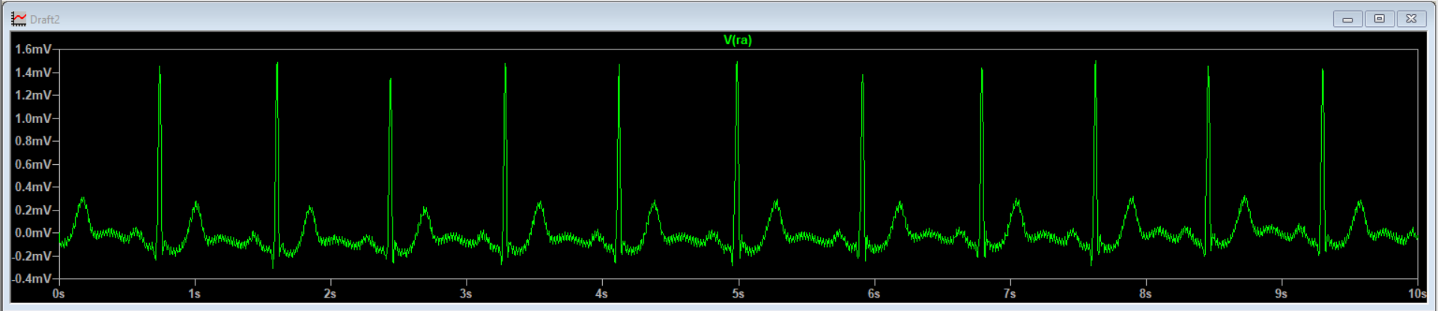
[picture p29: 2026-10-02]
Simulations/LTspice_Simulations/Simulation results/Before filter.png

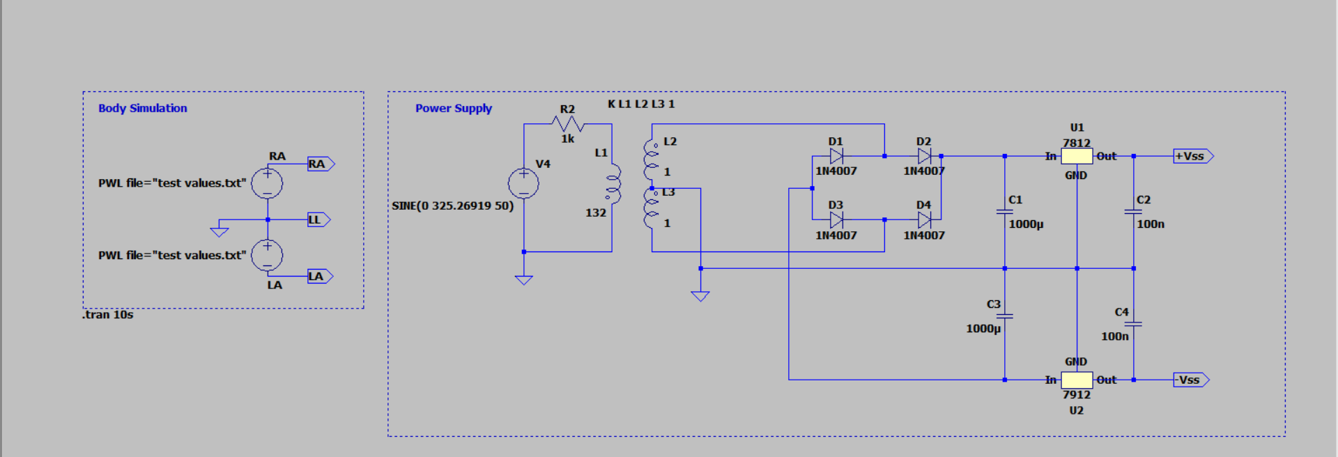
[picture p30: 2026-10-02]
Simulations/LTspice_Simulations/Simulation results/Body and Power supply.png

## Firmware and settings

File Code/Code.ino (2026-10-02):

#include <Adafruit_GFX.h>
#include <MCUFRIEND_kbv.h>
MCUFRIEND_kbv tft;


// Define color codes
#define BLACK 0x0000
#define BLUE 0x001F
#define GREEN 0x07E0
#define RED 0xF800
#define WHITE 0xFFFF

// Define variables for time intervals
unsigned long previousMillis1, previousMillis2 = 0;
const long interval1 = 20;
const long interval2 = 5;

void setup(void)
{
  Serial.begin(9600);

  // Initiate the display
  uint16_t ID = tft.readID();
  Serial.println("Example: Font_simple");
  Serial.print("found ID = 0x");
  Serial.println(ID, HEX);
  if (ID == 0xD3D3) ID = 0x9481; // force ID if write-only display
  tft.begin(ID);

  // Set screen orientation
  tft.setRotation(1);
  tft.fillScreen(BLACK);

  // Draw the grid
  drawGrid();
}

void loop() {
  unsigned long currentMillis = millis();

  // Task1 - Draw ECG graph
  if (currentMillis - previousMillis1 >= interval1) {
    previousMillis1 = currentMillis;
    runECG();
  }  
}

void drawGrid(){
  // Clear screen
  tft.fillScreen(BLACK);
  // Set text
  tft.setCursor(20, 20);
  tft.setTextColor(WHITE);
  tft.setTextColor(WHITE, BLACK); 
  tft.setTextSize(3);
  tft.println("ECG");

  // Draw vertical lines
  for (int i = 1; i <= 6; i++){
    tft.drawLine(80 * i,0,80*i, 320,BLUE);
  }

  // Draw horizontal lines
  for (int j = 1; j <= 4; j++){
    tft.drawLine(0,80 *j,480, 80*j,BLUE);
  }
}


void runECG(){
  // Read analog value from ADC pin
  long ecgValue = analogRead(34);

  // Normalize the value read to it screen size
  int normalizedVal = map(ecgValue, 0, 4095, 0, 320);

  static int lastX = 0;
  static int lastY = tft.height()/2 + 50;
  int x = lastX + 2;
  int y = tft.height() - normalizedVal;

  // Reset cursor if reached the right end of scren
  if (x >= tft.width()){
    x = 0;
    drawGrid();
    lastX = 0;
    lastY = tft.height()/2 + 50;
  
  }

  // Draw ECG line
  tft.drawLine(lastX, lastY, x, y, GREEN);
  lastX = x;
  lastY = y;
}
